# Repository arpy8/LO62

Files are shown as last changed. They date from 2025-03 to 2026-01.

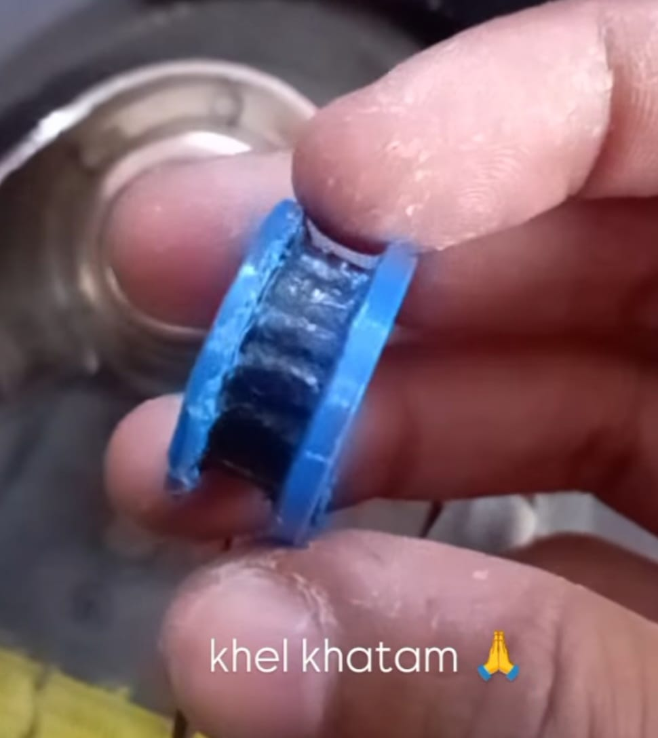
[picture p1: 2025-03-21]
misc/rip_little_pulley.png

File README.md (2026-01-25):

# LO62



# [Project Reel](https://www.instagram.com/p/DTc_H6qkeNk/)

### **Project Overview**  
LO62 is my electric ripstick project that I've been planning to build for almost 2 years now. I am using an ESP32 to control the BLDC motor with a timing belt mechanism. I also developed a mobile app using react native which you can find inside the [app](./app) directory for controlling the motor's speed in various ways.

I had planned to control the motor using a hand controller made from flex sensors as well but later dropped the idea because the onboard ESP32 couldn't handle both ble and esp-now at the same time due to limited space.

[Video for reference](https://www.reddit.com/r/developersIndia/comments/1huevbl/heres_me_controlling_a_bldc_motor_with_my_hand/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)

All source files, firmware and CAD designs are available in this repository. Alright bye.

## Materials Used
| Product | Link |
|---|---|
| Motor | [Turnigy Aerodrive SK3 6364 213KV Brushless Outrunner Motor](https://hobbyking.com/turnigy-aerodrive-sk3-6364-213kv-brushless-outrunner-motor.html) |
| Battery | [Orange 2200mAh 4S 40C/80C Lithium Polymer Battery Pack (LiPo)](https://robu.in/product/orange-2200mah-4s-40c80c-lithium-polymer-battery-pack-lipo/) |
| Battery Charger | [ISDT PD60 60W 6A Portable 1-4S Li-Po Balance Charger](https://robu.in/product/isdt-pd60-60w-6a-portable-1-4s-li-po-balance-charger/) |
| Timing Belt  | [5M Timing Belt Open Ended 10mm Width](https://www.amazon.in/5Mters-Timing-Ended-Pitch-Industrial/dp/B09M6RQJPD) |
| ESC 80A | [ReadytoSky 80A ESC 2-6S Brushless ESC Speed Controller for RC Drone](https://robu.in/product/readytosky-80a-esc-2-6s-brushless-esc-speed-controller-for-rc-drone/) |
| 3D Prints | [LO62 CAD Files (GitHub)](https://github.com/arpy8/LO62/tree/main/cad-files) |
| ESP32 | [ESP-WROOM-32 WiFi Bluetooth Development Board](https://robu.in/product/esp-wroom-32-wifi-bluetooth-networking-smart-component-development-board/) |

### **Diagram** 


### **Software & Firmware**  
- [Client Side Mobile App](./app)  
- [ESP32 Firmware Code](./firmware)

###  **License**  
- [MIT License](./LICENSE)

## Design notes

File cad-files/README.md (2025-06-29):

# STL Files  

This directory contains all the **STL (Stereolithography)** files required for the construction and assembly of this project.  
These designs were created using **Fusion 360** and later sliced using **Cura**.  

| Part Name | Image |
|---|---|
| Big Pulley |  |
| Big Pulley - Updated |  |
| Drivetrain |  |
| Drivetrain - Updated |  |
| Little Pulley |  |
| Outer Lid |  |

## Important Note

- The [main frame](./main_frame.stl) that connects the motor to the wheel is lowkey flawed. A lot of modifications were made after the prints arrived. (edit: the [updated drive train](./drivetrain_new.stl) you see is designed keeping in mind all the changes i made in the first version)
- Infill rate was set to **100%**
- Printing the [little pulley](./little_pulley.stl) was pointless as it was literally obliterated due to the immense load lmao ([image for reference](../misc/rip_little_pulley.png))

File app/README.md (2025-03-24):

# LO62 Controller Mobile App

This directory contains the source code for **LO62 Controller** built using React Native. The app connects with the onboard ESP32 via BLE.

## Screenshots

|  |  |  |
|---|---|---|

---

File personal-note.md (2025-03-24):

Back in my first semester, I used to ride my waveboard from my hostel to college. One day, I held onto my friend’s cycle for a little boost, IT WAS FUCKING INSANE.

That’s when it hit me, what if I could make it electric?

Now you see, unlike an electric skateboard, a waveboard’s wheels aren’t fixed. Hence I couldn’t just slap on a motor like a normal electric skateboard. I needed a different approach here.

I started exploring and looking into whether someone had attempted this before and found one guy who had done something similar (shoutout to eric for real). That gave me a starting point but the real struggle began when I had to design the drivetrain and integrate the motor system. Not to mention I almost lost the motor once because a tiny metal piece got stuck but thanks to the local repair waale bhaiya who managed to save it! 🙏

Rather than buying an expensive transceiver-receiver set, I decided to build my own motor control system. Controlling a BLDC motor is surprisingly simple — it only requires PWM signals. That’s it! Now, all I had to figure out was how to deliver those signals. To achieve this, I built a react native app using Expo that connects to my onboard ESP32 using bluetooth, which then links to the ESC. To speed up data transfer, I optimized the message size to fit within a single packet. And just like that, I had my controller ready!!

This project has taught me a lot, how motors work, the different types of belts, ESCs, and much more. Honestly, this could never have been made if my brother hadn’t bought me the motor, so a huge thanks to him for always supporting me.

There are several improvements that can be made and it’s far from perfect, but we’ll get there eventually. For now, I’m just enjoying the ride.

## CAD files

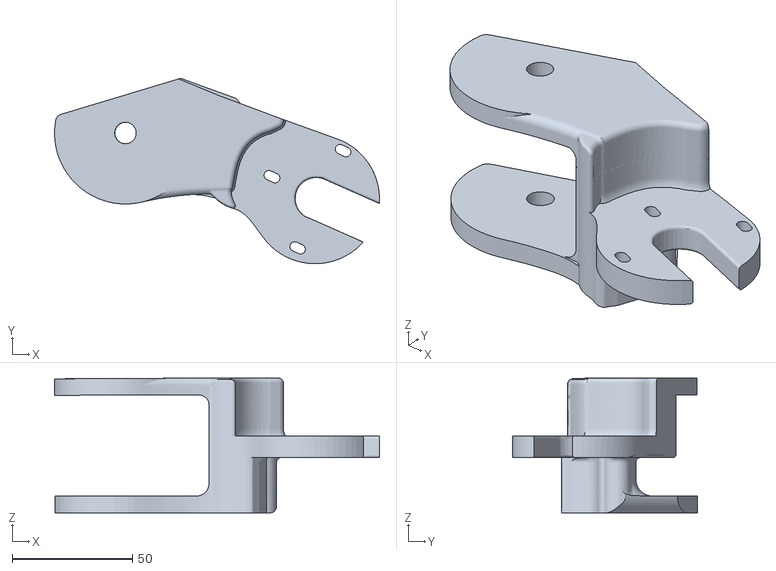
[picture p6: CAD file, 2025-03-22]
cad-files/drivetrain_new.stl
135.1 x 77.0 x 56.0

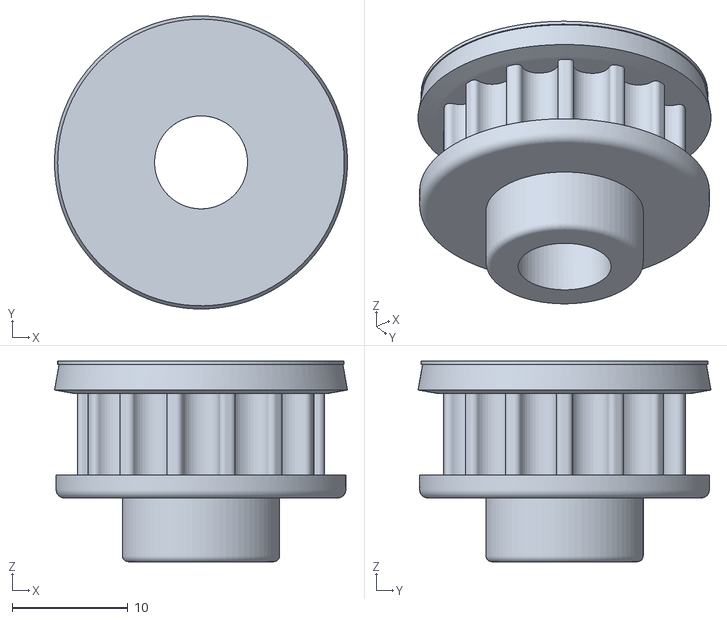
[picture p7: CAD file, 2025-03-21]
cad-files/little_pulley.stl
25.3 x 25.3 x 17.3

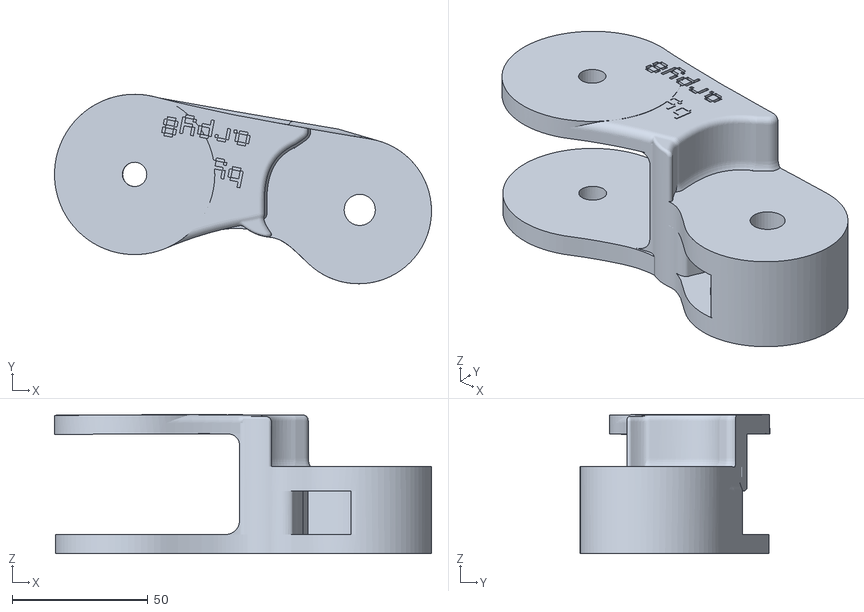
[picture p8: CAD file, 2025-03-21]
cad-files/drivetrain.stl
138.6 x 69.7 x 51.2

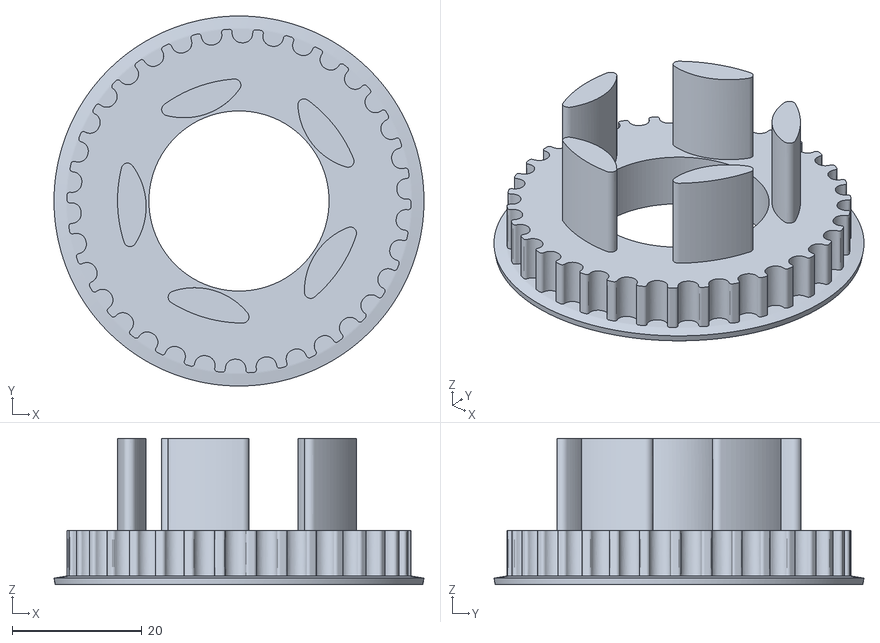
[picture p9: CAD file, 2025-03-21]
cad-files/big_pulley.stl
57.1 x 57.1 x 22.6

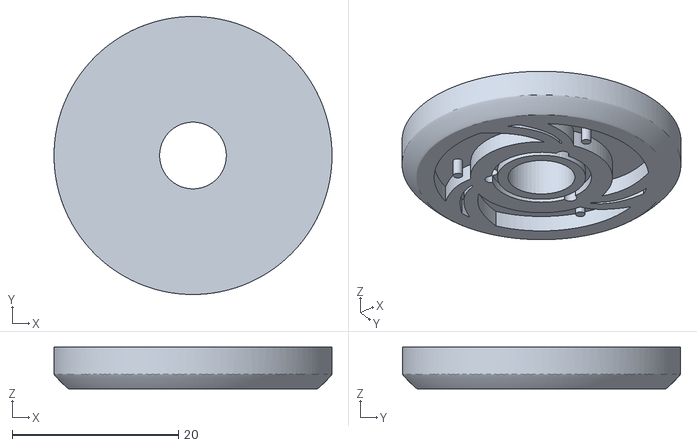
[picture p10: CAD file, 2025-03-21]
cad-files/outer lid.stl
33.4 x 33.4 x 5.00

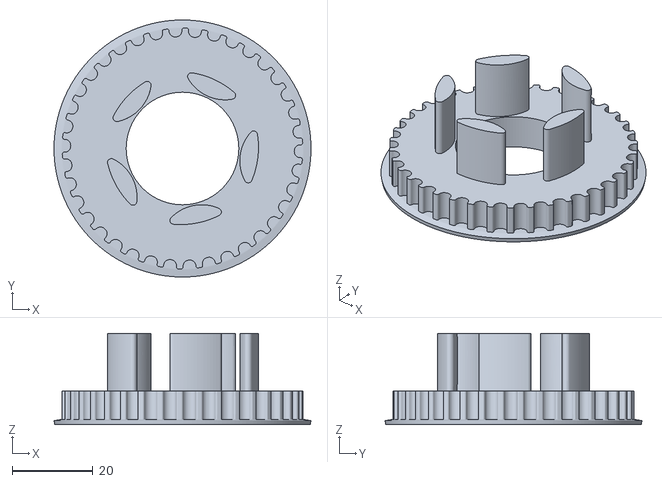
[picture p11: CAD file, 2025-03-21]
cad-files/big_big_pulley.stl
63.5 x 63.5 x 22.6

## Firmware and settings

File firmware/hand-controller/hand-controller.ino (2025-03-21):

#include "constants.h"
#include "bluetooth.h"
#include "utils.h"
#include "sensors.h"


void setup() {
  Serial.begin(115200);
  Serial.println("Starting...");

  setupSensor();
  setupBluetooth();
}

void loop() {
  if (!connected && doConnect) {
    if (connectToServer()) {
      Serial.println("Connected to board");
    } else {
      Serial.println("Failed to connect to the board");
      delay(5000);
    }
  }

  float thumbValue = analogRead(sensorPinThumb);
  float rawMiddle = analogRead(sensorPinMiddle);

  int normalizedMiddle = normalizeValue(rawMiddle, middleCal);
  // normalizedMiddle = map(abs(100 - normalizedMiddle), 1, 100, 20, 50);
  unsigned long currentMillis = millis();

  if (thumbValue < thresholdThumb) {
    if (thumbBelowThresholdStartTime == 0) {
      thumbBelowThresholdStartTime = currentMillis;
    } else if (currentMillis - thumbBelowThresholdStartTime > 2000) {
      if (currentMillis - lastThumbToggleTime > debounceDelay) {
        toggleEngine();
        lastThumbToggleTime = currentMillis;
      }
      thumbBelowThresholdStartTime = 0;
    }
  } else {
    thumbBelowThresholdStartTime = 0;
  }

  if (isEngineOn && normalizedMiddle % 2 == 0) {
    (normalizedMiddle > threshold) ? accelerate(100) : decelerate(100);

    Serial.print("Sent Speed: ");
    Serial.println(normalizedMiddle);

    int brightness = map(normalizedMiddle, 1, 100, 0, 255);
    analogWrite(LED_BUILTIN, brightness);
  } else {
    Serial.print(isEngineOn);
    Serial.print("\t");
    Serial.print(normalizedMiddle);
    Serial.print("\t");
    Serial.println(thumbValue);

    if (!isEngineOn || (normalizedMiddle <= threshold)) {
      previousSpeed = -1;
    }
  }

  delay(100);
}

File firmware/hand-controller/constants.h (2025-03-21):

#include "secrets.h"

#define LED_BT 2
#define sensorPinThumb 33
#define sensorPinMiddle 39
#define calibrationTime 5000

#define LED_BUILTIN 15
#define SERVICE_UUID "4fafc201-1fb5-459e-8fcc-c5c9c331914b"
#define CHAR_UUID "beb5483e-36e1-4688-b7f5-ea07361b26a8"

int previousSpeed = -1;
const int threshold = 60;
const int thresholdThumb = 200;
unsigned long lastThumbToggleTime = 0;
const unsigned long debounceDelay = 1000;
unsigned long thumbBelowThresholdStartTime = 0;

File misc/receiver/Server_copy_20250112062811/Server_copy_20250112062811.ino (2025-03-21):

#include <BLEDevice.h>
#include <BLEServer.h>
#include <BLEUtils.h>
#include <BLE2902.h>
#include <motor.h>

#define LED_BUILTIN 2
#define SERVICE_UUID "4fafc201-1fb5-459e-8fcc-c5c9c331914b"
#define CHARACTERISTIC_UUID "beb5483e-36e1-4688-b7f5-ea07361b26a8"

BLEServer* pServer = NULL;
BLECharacteristic* pCharacteristic = NULL;
bool deviceConnected = false;
unsigned long lastProcessTime = 0;
const int PROCESS_INTERVAL = 10;

class MyServerCallbacks : public BLEServerCallbacks {
  void onConnect(BLEServer* pServer) {
    deviceConnected = true;
    Serial.println("Device connected");
  };

  void onDisconnect(BLEServer* pServer) {
    deviceConnected = false;
    Serial.println("Device disconnected");
    BLEDevice::startAdvertising();
  }
};

class MyCharacteristicCallbacks : public BLECharacteristicCallbacks {
  void onWrite(BLECharacteristic* pCharacteristic) {
    String value = pCharacteristic->getValue();

    if (value.length() > 0) {
      processIncomingData(value);
    }
  }

private:
  void processIncomingData(const String& value) {
    const uint8_t* data = (const uint8_t*)value.c_str();
    int len = value.length();

    // 0x65: caliberate esc
    // default: handle speed

    if (len == 1) {
      Serial.println(data[0]);

      switch (data[0]) {
        case 0x65:
          recalibrateMotor();
          break;
        default:
          int receivedSpeed = data[0];
          setMotorSpeed(receivedSpeed);
          break;
      }
    }
  }
};

void setup() {
  setCpuFrequencyMhz(240);

  Serial.begin(115200);
  pinMode(LED_BUILTIN, OUTPUT);

  BLEDevice::init("ESP32_BLE");

  pServer = BLEDevice::createServer();
  pServer->setCallbacks(new MyServerCallbacks());

  BLEService* pService = pServer->createService(SERVICE_UUID);

  pCharacteristic = pService->createCharacteristic(
    CHARACTERISTIC_UUID,
    BLECharacteristic::PROPERTY_READ | BLECharacteristic::PROPERTY_WRITE | BLECharacteristic::PROPERTY_WRITE_NR | BLECharacteristic::PROPERTY_NOTIFY);

  pCharacteristic->setCallbacks(new MyCharacteristicCallbacks());
  pCharacteristic->addDescriptor(new BLE2902());

  pService->start();

  BLEAdvertising* pAdvertising = BLEDevice::getAdvertising();
  pAdvertising->addServiceUUID(SERVICE_UUID);
  pAdvertising->setScanResponse(true);
  pAdvertising->setMinPreferred(0x06);
  pAdvertising->setMaxPreferred(0x12);

  BLEDevice::startAdvertising();

  Serial.println(F("Ready!"));

  motorSetup();
}

void loop() {
  if (deviceConnected) {
    unsigned long currentTime = millis();

    if (currentTime - lastProcessTime >= PROCESS_INTERVAL) {
      lastProcessTime = currentTime;
    }
  } else {
    BLEDevice::startAdvertising();
    Serial.println("Waiting for connection...");
  }
}

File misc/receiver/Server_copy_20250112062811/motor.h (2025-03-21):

#include <ESP32Servo.h>

Servo motor;

const int motorPin = 13;
const int minPWM = 1000;    // min throttle
const int maxPWM = 2000;    // max throttle
const int inputMin = 1000;  // min input value
const int inputMax = 2000;  // max input value

unsigned long lastSignalTime = 0;
const unsigned long timeout = 500; // 500ms timeout
int motorSpeed = minPWM;

void motorSetup() {
  motor.setPeriodHertz(50); 
  motor.attach(motorPin, minPWM, maxPWM); 

  Serial.println(F("Arming ESC..."));
  motor.writeMicroseconds(minPWM);
  delay(2000);
  Serial.println(F("ESC armed."));
}

void decelerate(float step) {
  for (float speed = motorSpeed; speed >= minPWM; speed -= step) {
    motor.writeMicroseconds((int)speed);
    Serial.println(speed);
    delay(50);
  }
  motorSpeed = minPWM;
}

void accelerate(float step) {
  for (float speed = motorSpeed; speed <= maxPWM; speed += step) {
    motor.writeMicroseconds((int)speed);
    Serial.println(speed);
    delay(50);
  }
  motorSpeed = maxPWM;
}

void recalibrateMotor() {
  Serial.println(F("Starting ESC recalibration..."));

  Serial.println(F("Sending maximum throttle signal..."));
  motor.writeMicroseconds(maxPWM);
  delay(2000);

  Serial.println(F("Sending minimum throttle signal..."));
  motor.writeMicroseconds(minPWM);
  delay(2000);

  Serial.println(F("ESC recalibration complete. Returning to safe throttle."));
  motor.writeMicroseconds(minPWM);
  motorSpeed = minPWM;
}

void setMotorSpeed(int data) {
  motorSpeed = map(data, 0, 100, minPWM, maxPWM);
  
  Serial.print("Current Speed: ");
  motor.writeMicroseconds(motorSpeed);
}

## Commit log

2025-03-21 update directory structure
    [big_big_pulley.stl, big_pulley.stl, little_pulley.stl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]
2025-03-22 add new drivetrain
    [main_frame_new.stl]
